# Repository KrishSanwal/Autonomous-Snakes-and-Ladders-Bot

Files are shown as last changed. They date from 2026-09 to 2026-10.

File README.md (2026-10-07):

# Automatic Snakes and Ladders Board





A Snakes and Ladders board that plays against a human. A CoreXY mechanism is used under the board and it moves a gondola connected to a magnet, which drags the machine's piece across the board. Features sensorless homing as seen in many FDM printers.

> **Status: work in progress.** Hardware is being sourced. Firmware is not written yet. Items marked `[TBC]` are not finalised. Do not order parts from this README until those are resolved.

---

## Table of contents

1. [Overview](#overview)
   - [Features](#features)
2. [How it works](#how-it-works)
   - [Electronics](#electronics)
3. [Bill of materials](#bill-of-materials)
   - [Motion parts](#motion-parts)
   - [Electronic parts](#electronic-parts)
   - [Fasteners](#fasteners)
   - [Tools](#tools)
4. [3D Files](#3d-files)
   - [Full System with Top](#full-system-with-top)
   - [Full System](#full-system)
   - [Outer Frame](#outer-frame)
   - [Gondola System](#gondola-system)
   - [Top Cover](#top-cover)
6. [Wiring Diagram](#wiring-diagram)
7. [Licence](#licence)
8. [Author](#author)

---

## Overview

I made this project as there is a lot of use of CoreXY Mechanisms in large industrial machines such as CNCs, 3D Printers, Mills etc. Showcasing this mechanism through a board game makes it easy to understand as you do not have any other pieces except the ones needed for 2D movement.

### Features

- Plays a game of Snakes and Ladders against a human.
- Moves its own piece from under the board with a magnet, no visible mechanism.
- Remembers the position of the human's piece and it's piece so it knows who won.
- Sensor-less homing and therefore no limit switches are needed.
- Dice is rolled on an OLED display using a button.
- Runs on an Arduino Uno with a CNC Shield unit on it therefore does not need a custom PCB.

---

## How it works

This board uses a CoreXY Mechanism that consists of two static motors (motors don't move) on the front end of the board that control the main magnetic piece using timing belts. The movement happens by spinning either one of the motors or both of them. The motors move the magnetic gondola to set positions that translate to movement on the top board surface where a magnetic piece moves with the gondola. The game is played turn based and the dice is on a OLED screen activated by a push button. An E-Dice will help the machine know how much to move and also helps to tell the machine if the player has reached the end without the use of any physical sensors.

### Electronics

- Arduino Uno R3 with CNC Shield V3
- 2x NEMA 17 Stepper Motors
- 2x TMC2209 stepper drivers
- 1.3 inch I2C OLED for dice and messages
- 16 mm illuminated push button (Lanboo LB16QC, 5-24 V, 1NO)
- 5 V active buzzer
- 12 V 5 A supply with a rocker switch on the 12 V positive line

---

## Bill of materials

### Motion parts

| Qty | Part | Price (USD) | Price (INR) | Link |
|---:|---|---:|---:|---|
| 2 | StepperOnline 17HE15-1504S NEMA17 (42 N·cm, 1.5 A, 1 m detachable cable) | $15.64 | ₹1,498.00 | [Robu](https://robu.in/product/stepperonline-nema-17-42ncm-bipolar-stepper-motor/) |
| 2 (1 pack) | Aluminium GT2 20-tooth pulley, 5 mm bore, for 6 mm belt | $1.37 | ₹131.00 | [Robu](https://robu.in/product/aluminum-gt2-timing-pulley-for-6mm-belt-20-tooth-5mm-bore-2pcs/) |
| 8 | Flyrobo GT2 idler pulley without teeth, 5 mm bore, for 6 mm belt | $23.64 | ₹2,264.00 | [Amazon](https://www.amazon.in/gp/product/B0H7K3W1P3) |
| 2 | Self Lub GT2 timing belt 2 m x 6 mm, open | $9.38 | ₹898.00 | [Amazon](https://www.amazon.in/gp/product/B0HCLLLB88) |
| 6 (3 packs of 2) | INVENTO EN31 steel smooth rod 10 mm x 300 mm | $11.56 | ₹1,107.00 | [Amazon](https://www.amazon.in/gp/product/B071W8FKQV) |
| 8 | Two Trees SK10 (SH10A) rod support | $5.85 | ₹560.00 | [Robu](https://robu.in/product/sk10-10mm-linear-bearing-rail-support-xyz-shaft-table-cnc-router-sh10a/) |
| 4 | SC10UU 10 mm linear bearing block | $6.39 | ₹612.00 | [Robu](https://robu.in/product/sc10uu-10-mm-linear-ball-bearing-slide-unit-cnc-3d-printer/) |
| 1 pack | SNOOGG 12 x 2 mm N35 neodymium disc magnets (pack of 20) | $3.96 | ₹379.00 | [Amazon](https://www.amazon.in/gp/product/B0DMVKSZ74) |

### Electronic parts

| Qty | Part | Price (USD) | Price (INR) | Link |
|---:|---|---:|---:|---|
| 1 | Arduino Uno R3 with USB cable | $4.17 | ₹398.97 | [Robu](https://robu.in/product/arduino-uno-r3/) |
| 1 | CNC Shield V3 | $1.03 | ₹99.00 | [Robu](https://robu.in/product/cnc-shield-v3-engraving-machine-3d-printer-a4988-drv8825-driver-expansion-board/) |
| 2 | TMC2209 stepper driver module with heatsink (must expose DIAG and UART pins) | $13.55 | ₹1,298.00 | [Robu](https://robu.in/product/tmc2209-stepper-motor-driver-module-with-heatsink/) |
| 1 | 12 V 5 A 60 W power supply, 5.5 mm DC plug | $4.44 | ₹425.00 | [Robu](https://robu.in/product/orange-ac-100-240v-to-dc-12v-5a-60w-power-adapter/) |
| 1 | DC jack socket (female) with moulded wire lead, 15 cm | $0.22 | ₹21.00 | [Robu](https://robu.in/product/5mm-dc-jack-socket-female-jack-socket-with-wire/) |
| 1 | Electronic Spices DC female to 2 male Y-splitter cable | $1.24 | ₹119.00 | [Amazon](https://www.amazon.in/gp/product/B08PRS2Q23) |
| 1 | 6A 250V AC SPST ON-OFF rocker switch | $0.17 | ₹16.00 | [Robu](https://robu.in/product/6a-250v-ac-spst-on-off-rocker-switch/) |
| 1 | 1.3 inch I2C OLED display, blue | $3.02 | ₹289.00 | [Robu](https://robu.in/product/1-3-inch-i2c-iic-4-pin-oled-display-module-with-vcc-gnd-blue/) |
| 1 | Lanboo LB16QC-P10F 16 mm push button switch, blue, DC 5-24V, 1NO | $4.62 | ₹442.00 | [Robu](https://robu.in/product/lb16qc-p10f-lanboo-16mm-tact-push-button-switch-bluedc-5-24v1no/) |
| 1 | 5 V active buzzer | $0.17 | ₹16.00 | [Robu](https://robu.in/product/5v-active-electromagnetic-buzzer-pack-of-5/) |
| 17 (1 needed) | 1 kΩ 0.25 W metal film resistor (UART TX to RX link) | $0.11 | ₹10.20 | [Robu](https://robu.in/product/1k-ohm-0-25w-metal-film-resistor-pack-of-100/) |
| 2 | 1000 µF 25 V electrolytic capacitor (12 V input) | $0.23 | ₹22.00 | [Robu](https://robu.in/product/1000uf-25v-electrolytic-capacitor-dip-pack-of-5/) |
| 4 (3 needed, 2 works) | Rubycon 35ZLH100M 100 µF 35 V electrolytic capacitor (driver VMOT) | $0.16 | ₹15.64 | [Robu](https://robu.in/product/35zlh100mefct16-3x11-rubycon-100uf-35v-%c2%b120-plugind6-3xl11mm-aluminum-electrolytic-capacitors-leaded-rohs/) |
| 1 set | Dupont jumper wires, female-female, 20 cm, 40 pcs | $0.43 | ₹41.00 | [Robu](https://robu.in/product/20cm-dupont-wire-color-jumper-cable-2-54mm-1p-1p-female-female-40pcs/) |
| 1 set | Dupont jumper wires, male-female, 20 cm, 10 pcs | $0.14 | ₹13.00 | [Robu](https://robu.in/product/10-wire-male-to-female-jumper-wires-20cm/) |
| 4 | 3 mm black heat shrink sleeve | $0.25 | ₹24.00 | [Robu](https://robu.in/product/heat-shrink-sleeve-3mm-black-industrial-grade-woer-hst/) |

### Fasteners

| Qty | Part | Price (USD) | Price (INR) | Link |
|---:|---|---:|---:|---|
| 10 | M5 x 35mm Phillips pan head screw | $0.29 | ₹28.00 | [OnlyScrews](https://onlyscrews.in/products/m5-x-35mm-phillips-pan-head-mild-steel-with-zinc-blue-plating-screw-dia-5mm-length-35mm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) |
| 20 | M5 x 15mm Phillips pan head screw | $0.33 | ₹32.00 | [OnlyScrews](https://onlyscrews.in/products/m5-x-15mm-phillips-pan-head-mild-steel-with-zinc-blue-plating-screw-dia-5mm-length-15mm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) |
| 25 | M5 x 10mm Phillips pan head screw | $0.37 | ₹35.00 | [OnlyScrews](https://onlyscrews.in/products/m5-x-10mm-phillips-pan-head-mild-steel-with-zinc-blue-plating-screw-dia-5mm-length-10mm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) |
| 67 | M5 x 5mm brass threaded inserts | $1.54 | ₹147.40 | [OnlyScrews](https://onlyscrews.in/products/m5-x-5mm-brass-threaded-inserts-dia-5mm-length-5mm?variant=51217096835385) |
| 30 | M3 x 3mm brass threaded inserts | $0.75 | ₹72.00 | [OnlyScrews](https://onlyscrews.in/products/m3-x-3mm-brass-threaded-inserts?variant=49729062273337) |
| 25 | M5 plain washer SS304 (ID 5.4mm, OD 9.8mm, T 1mm) | $0.31 | ₹30.00 | [OnlyScrews](https://onlyscrews.in/products/m5-washer-ss304?variant=48883899105593) |
| 9 | M3 x 6mm Phillips pan head screw SS304 | $0.15 | ₹14.40 | [OnlyScrews](https://onlyscrews.in/products/phillips-pan-head-m3-x-6mm-pack-of-20?variant=48468588757305) |
| 15 | M3 x 10mm Phillips pan head screw SS304 | $0.28 | ₹27.00 | [OnlyScrews](https://onlyscrews.in/products/phillips-pan-head-m3-x-10mm-pack-of-20?variant=48468583874873) |
| 5 | M3 x 16mm Phillips pan head screw SS304 | $0.11 | ₹11.00 | [OnlyScrews](https://onlyscrews.in/products/phillips-pan-head-m3-x-16mm-pack-of-20?variant=48468578959673) |
| 4 | M5 hex nut SS304 | $0.058 | ₹5.60 | [OnlyScrews](https://onlyscrews.in/a/search?q=m5+nut&options%5Bprefix%5D=last) |

### Tools

| Qty | Part | Price (USD) | Price (INR) | Link |
|---:|---|---:|---:|---|
| 1 | UNI-T UT890D+ digital multimeter, True RMS 6000 count | $19.83 | ₹1,899.00 | [Robu](https://robu.in/product/uni-t-ut890d-digital-multimeter/) |
| 1 | Serplex 12-in-1 soldering iron tool kit 80W | $16.70 | ₹1,599.00 | [Amazon](https://www.amazon.in/gp/product/B0G2H4J193) |

3D printer: parts here are made on a Bambu Lab P2S.

### Total

**~$154 (₹14,599.21)**

---

## 3D Files

### Full System With Top



### Full System



### Outer Frame



### Gondola System



## Top Cover



---

## Wiring Diagram
This project does not use a custom PCB rather relies on an Arduino Board with a CNC Shield Attachment.



---

## Licence

Licensed under CC BY-NC-SA 4.0. See [LICENSE](LICENSE).

Personal, educational and classroom use is welcome. You may build it, modify it and share your changes under the same licence, with credit.

Selling is not permitted: no assembled units, kits, printed parts, files or firmware, original or modified. For commercial licensing, contact me.

This project is source-available, not open source as defined by OSI or OSHWA.

Third-party libraries remain under their own licences.

---

## Author

Krish Sanwal
https://github.com/KrishSanwal

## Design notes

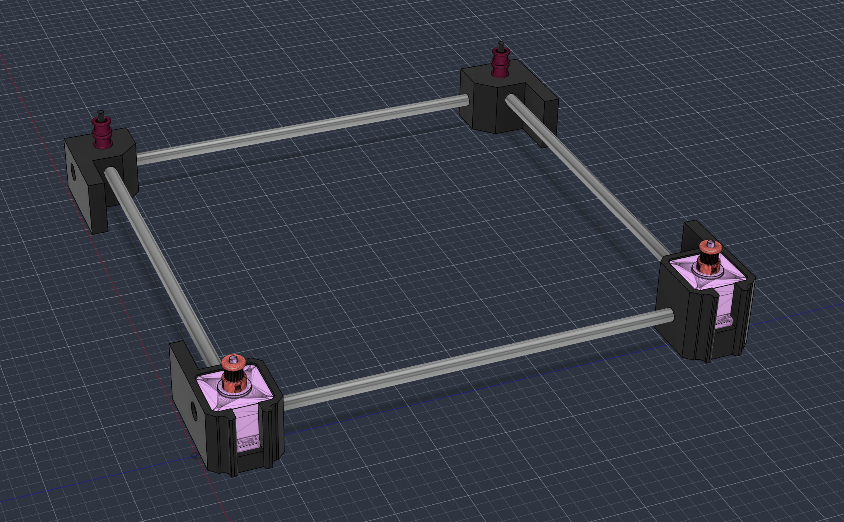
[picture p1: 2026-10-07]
3D Files/Outer Frame.png

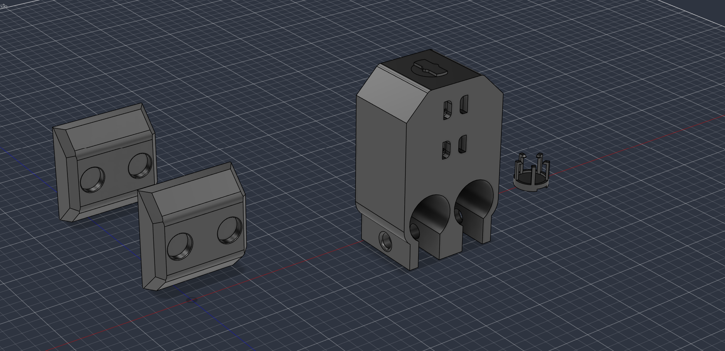
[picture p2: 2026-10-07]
3D Files/Gondola Sliding System.png

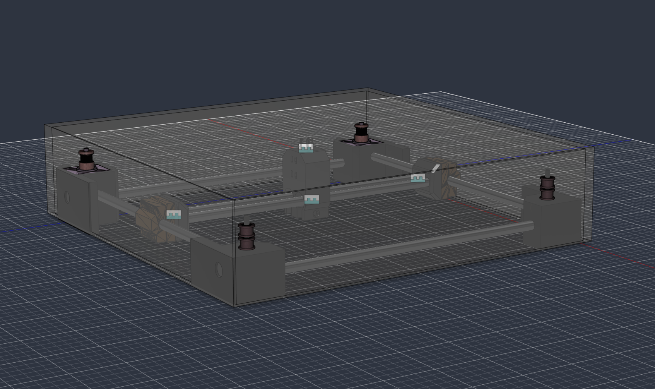
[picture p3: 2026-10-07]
3D Files/Complete Board Asembly.png

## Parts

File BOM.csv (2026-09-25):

Item Name | Qty | Price (total) (USD) | Item link | Notes
Two Trees SH10A SK10 10mm linear bearing rail support | 8 | $5.85 (INR 560.00) | https://robu.in/product/sk10-10mm-linear-bearing-rail-support-xyz-shaft-table-cnc-router-sh10a/
SC10UU 10 mm linear ball bearing slide unit | 4 | $6.39 (INR 612.00) | https://robu.in/product/sc10uu-10-mm-linear-ball-bearing-slide-unit-cnc-3d-printer/
Aluminum GT2 timing pulley 20 tooth 5mm bore for 6mm belt (2 pcs) | 1 | $1.37 (INR 131.00) | https://robu.in/product/aluminum-gt2-timing-pulley-for-6mm-belt-20-tooth-5mm-bore-2pcs/
Arduino Uno R3 with cable | 1 | $4.17 (INR 398.97) | https://robu.in/product/arduino-uno-r3/
CNC Shield V3 | 1 | $1.03 (INR 99.00) | https://robu.in/product/cnc-shield-v3-engraving-machine-3d-printer-a4988-drv8825-driver-expansion-board/
TMC2209 stepper motor driver module with heatsink | 2 | $13.55 (INR 1298.00) | https://robu.in/product/tmc2209-stepper-motor-driver-module-with-heatsink/
Standard 12V 5A 60W power supply with 5.5mm DC plug | 1 | $4.44 (INR 425.00) | https://robu.in/product/orange-ac-100-240v-to-dc-12v-5a-60w-power-adapter/
20cm Dupont jumper cable female to female, 40 pcs | 1 | $0.43 (INR 41.00) | https://robu.in/product/20cm-dupont-wire-color-jumper-cable-2-54mm-1p-1p-female-female-40pcs/
10 wire male to female jumper wires, 20cm | 1 | $0.14 (INR 13.00) | https://robu.in/product/10-wire-male-to-female-jumper-wires-20cm/
1k ohm 0.25W metal film resistor | 17 | $0.11 (INR 10.20) | https://robu.in/product/1k-ohm-0-25w-metal-film-resistor-pack-of-100/ | 1 needed, 16 extra as the site im ordering from (robu.in) does not allow ordering components below 10 rupees
1000uF 25V electrolytic capacitor | 2 | $0.23 (INR 22.00) | https://robu.in/product/1000uf-25v-electrolytic-capacitor-dip-pack-of-5/ | 1 needed, 1 extra
Rubycon 35ZLH100M 100uF 35V electrolytic capacitor | 4 | $0.16 (INR 15.64) | https://robu.in/product/35zlh100mefct16-3x11-rubycon-100uf-35v-%c2%b120-plugind6-3xl11mm-aluminum-electrolytic-capacitors-leaded-rohs/ | 3 needed, 1 extra
Heat shrink sleeve 3mm black (WOER) | 4 | $0.25 (INR 24.00) | https://robu.in/product/heat-shrink-sleeve-3mm-black-industrial-grade-woer-hst/
StepperOnline 17HE15-1504S NEMA17 stepper motor 42Ncm 1.5A with 1m cable | 2 | $15.64 (INR 1498.00) | https://robu.in/product/stepperonline-nema-17-42ncm-bipolar-stepper-motor/
5mm DC jack socket female connector with moulded wire, 15cm | 1 | $0.22 (INR 21.00) | https://robu.in/product/5mm-dc-jack-socket-female-jack-socket-with-wire/
1.3 inch I2C 4 pin OLED display module, blue | 1 | $3.02 (INR 289.00) | https://robu.in/product/1-3-inch-i2c-iic-4-pin-oled-display-module-with-vcc-gnd-blue/
5V active electromagnetic buzzer | 1 | $0.17 (INR 16.00) | https://robu.in/product/5v-active-electromagnetic-buzzer-pack-of-5/
Lanboo LB16QC-P10F 16mm push button switch, blue, DC 5-24V, 1NO | 1 | $4.62 (INR 442.00) | https://robu.in/product/lb16qc-p10f-lanboo-16mm-tact-push-button-switch-bluedc-5-24v1no/
6A 250V AC SPST ON-OFF rocker switch | 1 | $0.17 (INR 16.00) | https://robu.in/product/6a-250v-ac-spst-on-off-rocker-switch/
UNI-T UT890D+ digital multimeter, True RMS 6000 count | 1 | $19.83 (INR 1899.00) | https://robu.in/product/uni-t-ut890d-digital-multimeter/
Serplex 12-in-1 soldering iron tool kit 80W | 1 | $16.70 (INR 1599.00) | https://www.amazon.in/gp/product/B0G2H4J193
Electronic Spices DC female to 2 male Y-splitter cable | 1 | $1.24 (INR 119.00) | https://www.amazon.in/gp/product/B08PRS2Q23
INVENTO EN31 steel smooth rod 10mm x 300mm (2 pcs) | 3 | $11.56 (INR 1107.00) | https://www.amazon.in/gp/product/B071W8FKQV
SNOOGG 12 x 2 mm N35 neodymium disc magnets, pack of 20 | 1 | $3.96 (INR 379.00) | https://www.amazon.in/gp/product/B0DMVKSZ74
Flyrobo GT2 idler pulley without teeth, 5mm bore, for 6mm belt | 8 | $23.64 (INR 2264.00) | https://www.amazon.in/gp/product/B0H7K3W1P3
Self Lub GT2 timing belt 2 m x 6mm, open | 2 | $9.38 (INR 898.00) | https://www.amazon.in/gp/product/B0HCLLLB88
M5 x 35mm Phillips pan head screw | 10 | $0.29 (INR 28.00) | https://onlyscrews.in/products/m5-x-35mm-phillips-pan-head-mild-steel-with-zinc-blue-plating-screw-dia-5mm-length-35mm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
M5 x 15mm Phillips pan head screw | 20 | $0.33 (INR 32.00) | https://onlyscrews.in/products/m5-x-15mm-phillips-pan-head-mild-steel-with-zinc-blue-plating-screw-dia-5mm-length-15mm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
M5 x 10mm Phillips pan head screw | 25 | $0.37 (INR 35.00) | https://onlyscrews.in/products/m5-x-10mm-phillips-pan-head-mild-steel-with-zinc-blue-plating-screw-dia-5mm-length-10mm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
M5 x 5mm brass threaded inserts | 67 | $1.54 (INR 147.40) | https://onlyscrews.in/products/m5-x-5mm-brass-threaded-inserts-dia-5mm-length-5mm?variant=51217096835385
M3 x 3mm Brass Threaded Inserts | 30 | $0.75 (INR 72.00) | https://onlyscrews.in/products/m3-x-3mm-brass-threaded-inserts?variant=49729062273337
M5 plain washer SS304 (ID 5.4mm, OD 9.8mm, T 1mm) | 25 | $0.31 (INR 30.00) | https://onlyscrews.in/products/m5-washer-ss304?variant=48883899105593
M3 x 6mm Phillips pan head screw SS304 | 9 | $0.15 (INR 14.40) | https://onlyscrews.in/products/phillips-pan-head-m3-x-6mm-pack-of-20?variant=48468588757305
M3 x 10mm Phillips pan head screw SS304 | 15 | $0.28 (INR 27.00) | https://onlyscrews.in/products/phillips-pan-head-m3-x-10mm-pack-of-20?variant=48468583874873
M3 x 16mm Phillips pan head screw SS304 | 5 | $0.11 (INR 11.00) | https://onlyscrews.in/products/phillips-pan-head-m3-x-16mm-pack-of-20?variant=48468578959673
M5 Hex Nut SS304 | 4 | $0.058 (INR 5.60) | https://onlyscrews.in/a/search?q=m5+nut&options%5Bprefix%5D=last
Total Price (USD): | ~$154 (INR 14,599.21) |  |  | 1 USD = 95.77 INR

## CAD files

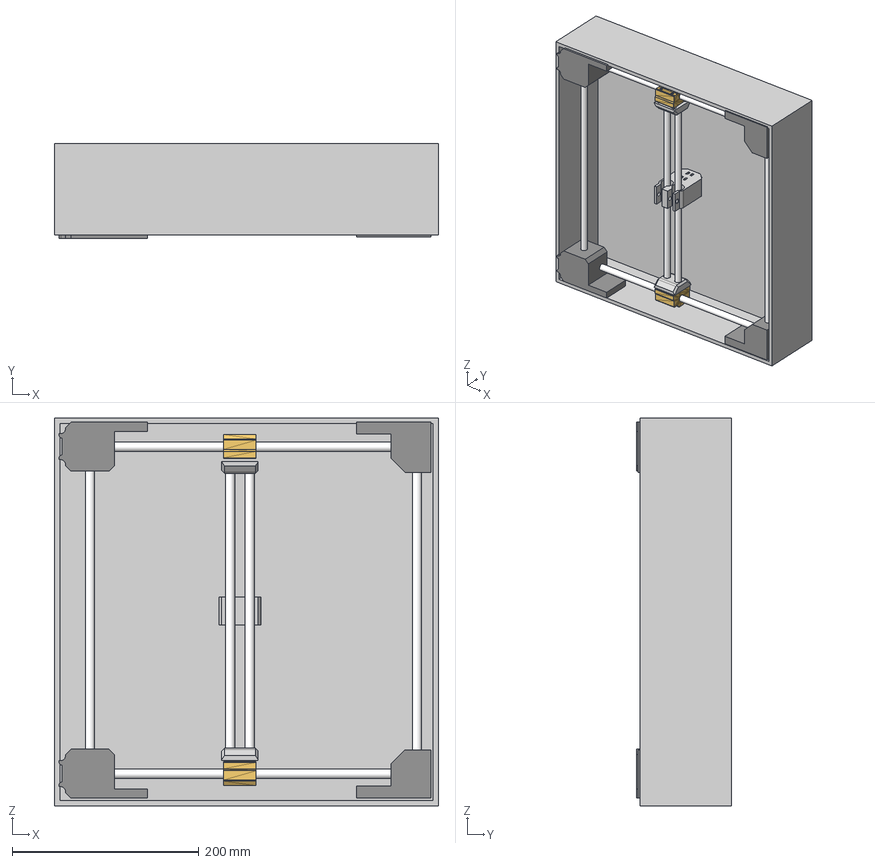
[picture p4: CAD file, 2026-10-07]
3D Files/CoreXY Snakes And Ladders Board Assembly.step
411.0 x 101.3 x 415.0 mm

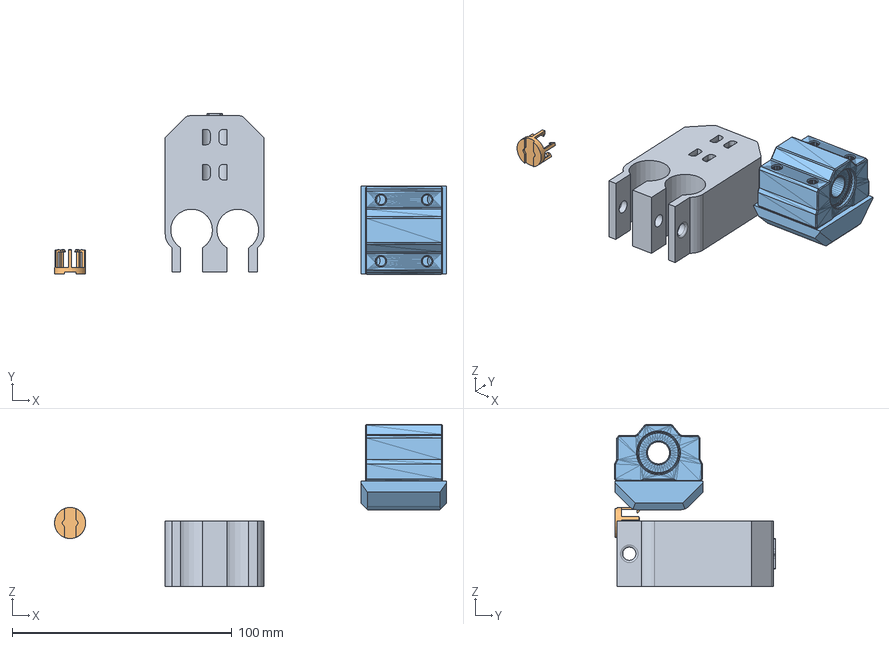
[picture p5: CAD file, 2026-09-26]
3D Files/Gondola Sliding system.step
178.4 x 73.2 x 73.9 mm

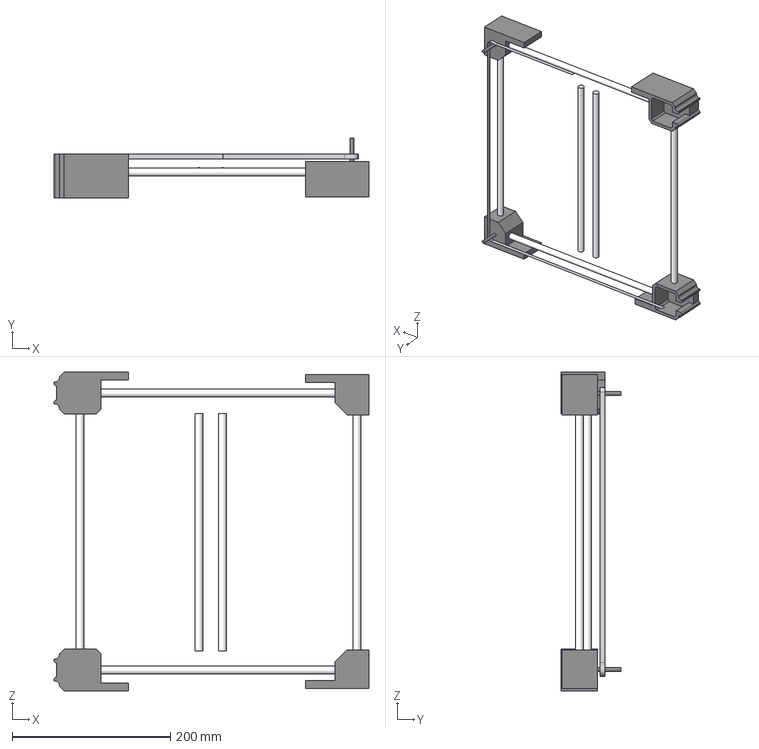
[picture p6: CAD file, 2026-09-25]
3D Files/Outer Frame.step
398.0 x 76.0 x 402.6 mm

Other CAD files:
3D Files/CoreXY Assembly.f3z
3D Files/Gondola Sliding system.f3d
3D Files/Outer Frame.f3d

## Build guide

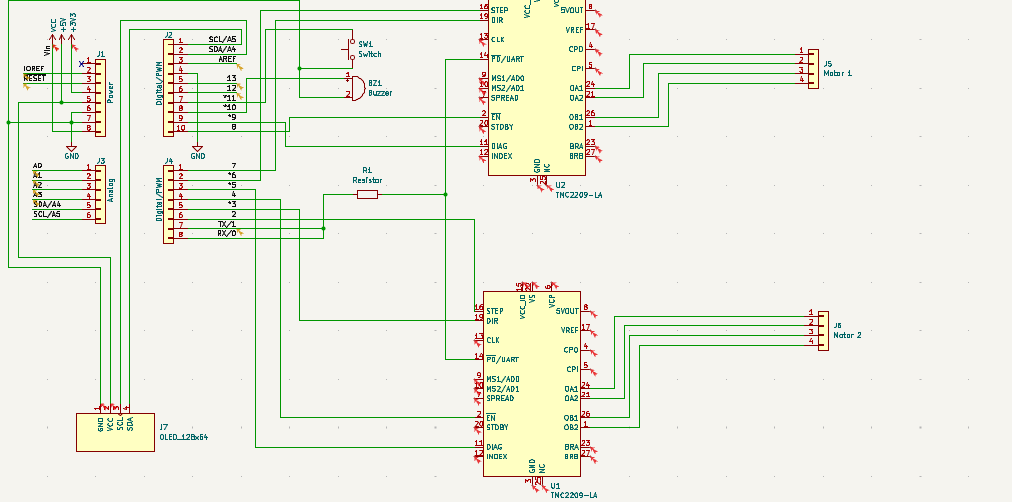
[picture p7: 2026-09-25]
Wiring/Wiring Schematic.png

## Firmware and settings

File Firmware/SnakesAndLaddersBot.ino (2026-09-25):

// Autonomous Snakes & Ladders Bot
// CoreXY gondola under the board drags a magnetic piece to each square.
// TMC2209 sensorless homing, shared single-wire UART, OLED status display.
//
// Libraries required (Library Manager):
//   TMCStepper      by teemuatlut
//   AccelStepper    by Mike McCauley
//   Adafruit GFX Library
//   Adafruit SSD1306

#include <TMCStepper.h>
#include <AccelStepper.h>
#include <Wire.h>
#include <Adafruit_GFX.h>
#include <Adafruit_SSD1306.h>
#include <EEPROM.h>
#include "config.h"

// ---- drivers (share one Serial/UART bus, told apart by address) ----
TMC2209Stepper driverA(&Serial, R_SENSE, DRIVER_ADDR_A);
TMC2209Stepper driverB(&Serial, R_SENSE, DRIVER_ADDR_B);

// ---- steppers ----
AccelStepper stepperA(AccelStepper::DRIVER, STEP_A_PIN, DIR_A_PIN);
AccelStepper stepperB(AccelStepper::DRIVER, STEP_B_PIN, DIR_B_PIN);

// ---- OLED ----
#define SCREEN_WIDTH 128
#define SCREEN_HEIGHT 64
Adafruit_SSD1306 display(SCREEN_WIDTH, SCREEN_HEIGHT, &Wire, -1);

// The bot only has a magnet for its OWN piece, but the roll (dice) is
// onboard and used for BOTH turns, so software has to track both
// players' squares to know who's ahead and who's won.
int humanSquare = 1;
int botSquare = 1;

// EEPROM layout: [0]=magic byte, [1]=humanSquare, [2]=botSquare
#define EEPROM_MAGIC_ADDR    0
#define EEPROM_HUMAN_ADDR    1
#define EEPROM_BOT_ADDR      2
#define EEPROM_MAGIC_VALUE   0x5A   // marks "state has been saved at least once"

void saveState() {
  EEPROM.update(EEPROM_MAGIC_ADDR, EEPROM_MAGIC_VALUE);
  EEPROM.update(EEPROM_HUMAN_ADDR, (uint8_t)humanSquare);
  EEPROM.update(EEPROM_BOT_ADDR, (uint8_t)botSquare);
}

bool loadState() {
  if (EEPROM.read(EEPROM_MAGIC_ADDR) != EEPROM_MAGIC_VALUE) return false; // nothing saved yet
  humanSquare = EEPROM.read(EEPROM_HUMAN_ADDR);
  botSquare = EEPROM.read(EEPROM_BOT_ADDR);
  if (humanSquare < 1 || humanSquare > 100) humanSquare = 1; // sanity check
  if (botSquare < 1 || botSquare > 100) botSquare = 1;
  return true;
}

// ============================================================
// SETUP
// ============================================================
void setup() {
  pinMode(EN_A_PIN, OUTPUT);
  pinMode(EN_B_PIN, OUTPUT);
  pinMode(DIAG_A_PIN, INPUT);
  pinMode(DIAG_B_PIN, INPUT);
  pinMode(BUTTON_PIN, INPUT_PULLUP);
  pinMode(BUZZER_PIN, OUTPUT);

  digitalWrite(EN_A_PIN, LOW);   // active LOW = enabled
  digitalWrite(EN_B_PIN, LOW);

  Serial.begin(115200);          // this is the shared TMC2209 UART bus, not a USB debug console
  driverA.begin();
  driverB.begin();
  setupDriver(driverA);
  setupDriver(driverB);

  stepperA.setMaxSpeed(RUN_SPEED_SPS);
  stepperA.setAcceleration(RUN_ACCEL_SPS2);
  stepperB.setMaxSpeed(RUN_SPEED_SPS);
  stepperB.setAcceleration(RUN_ACCEL_SPS2);

  Wire.begin();
  display.begin(SSD1306_SWITCHCAPVCC, 0x3C);
  showMessage("Booting...");

  randomSeed(analogRead(A0));   // leave A0 floating/unconnected — needed for real randomness

  bool resumed = loadState();   // false on very first boot ever, or if EEPROM was blank

  homeAxes();                    // motors always need a fresh physical reference after power-up

  if (!resumed) {
    humanSquare = 1;
    botSquare = 1;
    saveState();
  }
  moveToSquare(botSquare);       // put the gondola back where the bot's piece actually was
  showStatus();
}

// Common per-driver config. TMC2209 loses this on every power cycle,
// which is why it lives in setup() rather than being a one-time flash.
void setupDriver(TMC2209Stepper &drv) {
  drv.toff(5);
  drv.rms_current(MOTOR_RMS_CURRENT_MA);
  drv.microsteps(MICROSTEPS);
  drv.en_spreadCycle(false);      // stealthChop for quiet running
  drv.pwm_autoscale(true);
  drv.TCOOLTHRS(0xFFFFF);         // enable StallGuard across full speed range for homing
  drv.SGTHRS(STALLGUARD_THRESHOLD);
}

// ============================================================
// MAIN LOOP
// ============================================================
bool gameOver = false;

void loop() {
  if (!gameOver && digitalRead(BUTTON_PIN) == LOW) {
    delay(30);                    // debounce
    if (digitalRead(BUTTON_PIN) == LOW) {
      playRound();
      while (digitalRead(BUTTON_PIN) == LOW) { /* wait for release */ }
    }
  }
}

// ============================================================
// GAME LOGIC
// One button press = one full round: human rolls (onboard dice,
// software-only move — human slides their own piece by hand to
// match the displayed number), then the bot auto-rolls and the
// gondola physically drives its piece there.
// ============================================================
void playRound() {
  // ---- human's roll ----
  int humanRoll = random(1, 7);
  showMessage(("Your roll: " + String(humanRoll)).c_str());
  beep(1);
  delay(1200);   // give them time to read it and move their piece by hand

  int humanTarget = humanSquare + humanRoll;
  if (humanTarget > 100) humanTarget = humanSquare; // must land exactly on 100
  humanSquare = applyJump(humanTarget, false);
  saveState();   // saved here, after humanSquare holds the final post-jump value

  if (humanSquare == 100) {
    endGame("You win!");
    return;
  }

  // ---- bot's roll, automatic, no second button press ----
  delay(600);
  int botRoll = random(1, 7);
  showMessage(("Bot roll: " + String(botRoll)).c_str());
  delay(500);

  int botTarget = botSquare + botRoll;
  if (botTarget > 100) botTarget = botSquare;

  moveToSquare(botTarget);
  botSquare = botTarget;
  saveState();   // save right after the physical move so gondola position always matches saved square

  botSquare = applyJump(botSquare, true);
  saveState();   // saved here, after botSquare holds the final post-jump value

  if (botSquare == 100) {
    endGame("Bot wins!");
    return;
  }

  showStatus();
}

// Checks a square for a snake/ladder, beeps, and — for the bot only —
// physically drives the gondola to the destination. Returns the
// final resting square after any jump.
int applyJump(int square, bool isBot) {
  int jumped = checkSnakeOrLadder(square);
  if (jumped == square) {
    beep(1);
    return square;
  }
  delay(400);
  bool isLadder = jumped > square;
  beep(isLadder ? 2 : 1);         // 2 short beeps = ladder, 1 long = snake
  if (isBot) {
    moveToSquare(jumped);
  }
  return jumped;
}

void endGame(const char *msg) {
  gameOver = true;
  saveState();
  showMessage(msg);
}

int checkSnakeOrLadder(int square) {
  for (int i = 0; i < NUM_JUMPS; i++) {
    if (SNAKES_AND_LADDERS[i].from == square) {
      return SNAKES_AND_LADDERS[i].to;
    }
  }
  return square;
}

// ============================================================
// SQUARE -> BOARD COORDINATE (boustrophedon numbering)
// Square 1 = bottom-left, row 0 goes left->right,
// row 1 goes right->left, and so on.
// ============================================================
void squareToXY(int square, float &xmm, float &ymm) {
  int idx = square - 1;
  int row = idx / BOARD_SIZE;
  int col = idx % BOARD_SIZE;
  if (row % 2 == 1) col = (BOARD_SIZE - 1) - col;

  xmm = col * SQUARE_SIZE_MM + SQUARE_SIZE_MM / 2.0f;
  ymm = row * SQUARE_SIZE_MM + SQUARE_SIZE_MM / 2.0f;
}

void moveToSquare(int square) {
  float x, y;
  squareToXY(square, x, y);
  moveToXY(x, y);
}

// ============================================================
// CoreXY MOTION
// stepsA = x + y, stepsB = x - y  (relative to the homed corner)
// ============================================================
void moveToXY(float xmm, float ymm) {
  long xSteps = lround(xmm * STEPS_PER_MM);
  long ySteps = lround(ymm * STEPS_PER_MM);

  long targetA = xSteps + ySteps;
  long targetB = xSteps - ySteps;

  stepperA.moveTo(targetA);
  stepperB.moveTo(targetB);

  while (stepperA.distanceToGo() != 0 || stepperB.distanceToGo() != 0) {
    stepperA.run();
    stepperB.run();
  }
}

// ============================================================
// SENSORLESS HOMING
// Moves both motors together (equal sign = pure X, opposite
// sign = pure Y) until either DIAG pin flags a stall.
// ============================================================
void homeAxes() {
  showMessage("Homing X...");
  homeOneAxis(true);   // pure X
  showMessage("Homing Y...");
  homeOneAxis(false);  // pure Y

  stepperA.setCurrentPosition(0);
  stepperB.setCurrentPosition(0);
}

void homeOneAxis(bool isX) {
  long maxSteps = lround(HOMING_MAX_TRAVEL_MM * STEPS_PER_MM);
  long backoffSteps = lround(HOMING_BACKOFF_MM * STEPS_PER_MM);

  stepperA.setMaxSpeed(HOMING_SPEED_SPS);
  stepperA.setAcceleration(HOMING_ACCEL_SPS2);
  stepperB.setMaxSpeed(HOMING_SPEED_SPS);
  stepperB.setAcceleration(HOMING_ACCEL_SPS2);

  // isX: both motors move the same direction -> pure X travel
  // !isX: motors move opposite directions -> pure Y travel
  stepperA.move(-maxSteps);
  stepperB.move(isX ? -maxSteps : maxSteps);

  bool stalled = false;
  while (!stalled && (stepperA.distanceToGo() != 0 || stepperB.distanceToGo() != 0)) {
    if (digitalRead(DIAG_A_PIN) == HIGH || digitalRead(DIAG_B_PIN) == HIGH) {
      stalled = true;
      break;
    }
    stepperA.run();
    stepperB.run();
  }

  stepperA.stop();
  stepperB.stop();
  stepperA.setCurrentPosition(stepperA.currentPosition());
  stepperB.setCurrentPosition(stepperB.currentPosition());

  // back off the corner
  stepperA.move(isX ? backoffSteps : backoffSteps);
  stepperB.move(isX ? backoffSteps : -backoffSteps);
  while (stepperA.distanceToGo() != 0 || stepperB.distanceToGo() != 0) {
    stepperA.run();
    stepperB.run();
  }

  stepperA.setMaxSpeed(RUN_SPEED_SPS);
  stepperA.setAcceleration(RUN_ACCEL_SPS2);
  stepperB.setMaxSpeed(RUN_SPEED_SPS);
  stepperB.setAcceleration(RUN_ACCEL_SPS2);
}

// ============================================================
// OLED + BUZZER HELPERS
// ============================================================
void showMessage(const char *msg) {
  display.clearDisplay();
  display.setTextSize(1);
  display.setTextColor(SSD1306_WHITE);
  display.setCursor(0, 0);
  display.println(msg);
  display.display();
}

void showStatus() {
  display.clearDisplay();
  display.setTextSize(1);
  display.setTextColor(SSD1306_WHITE);
  display.setCursor(0, 0);
  display.println("Snakes & Ladders");
  display.setCursor(0, 16);
  display.print("You: ");
  display.println(humanSquare);
  display.setCursor(0, 28);
  display.print("Bot: ");
  display.println(botSquare);
  display.setCursor(0, 50);
  display.println("Press button to roll");
  display.display();
}

void beep(int times) {
  for (int i = 0; i < times; i++) {
    tone(BUZZER_PIN, 2000, 150);
    delay(200);
  }
}

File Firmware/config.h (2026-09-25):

#pragma once

// ============================================================
// PIN MAP — matches the KiCad schematic wiring table
// ============================================================
// Driver A = U1, UART address 0 (MS1/AD0 tied to GND)
//   -> physically wired to motor connector J6 ("Motor 2" on schematic)
// Driver B = U2, UART address 1 (MS1/AD0 tied to VCC_IO)
//   -> physically wired to motor connector J5 ("Motor 1" on schematic)
// If you want the silkscreen labels to match, swap the two
// TMC2209Stepper objects in the .ino instead of rewiring.

#define STEP_A_PIN   2
#define DIR_A_PIN    3
#define EN_A_PIN     4
#define DIAG_A_PIN   5

#define STEP_B_PIN   6
#define DIR_B_PIN    7
#define EN_B_PIN     8
#define DIAG_B_PIN   9

#define BUZZER_PIN   10
#define BUTTON_PIN   11

// UART bus: shared PD/UART line on both drivers, joined to
// Arduino D0 (RX) / D1 (TX) through the 1k resistor (R1).
// This means the USB serial monitor is NOT available for debug
// prints while the drivers are active — use the OLED for status.
#define DRIVER_ADDR_A   0b00
#define DRIVER_ADDR_B   0b01
#define R_SENSE         0.11f   // check your TMC2209 module's sense resistor silkscreen — common value, not guaranteed

// ============================================================
// MOTION / CoreXY CONSTANTS — tune these to your actual build
// ============================================================
#define STEPS_PER_REV     200     // 1.8° NEMA17
#define MICROSTEPS        16      // set to match driver config below
#define PULLEY_TEETH      20      // GT2 20T pulley
#define BELT_PITCH_MM     2.0f    // GT2 = 2mm pitch
#define MM_PER_REV        (PULLEY_TEETH * BELT_PITCH_MM)                // 40mm
#define STEPS_PER_MM      ((STEPS_PER_REV * MICROSTEPS) / MM_PER_REV)   // 80 steps/mm at 16x

#define HOMING_SPEED_SPS      400   // steps/sec while seeking the stall
#define HOMING_ACCEL_SPS2     200
#define HOMING_BACKOFF_MM     5.0f
#define HOMING_MAX_TRAVEL_MM  350.0f  // generous over-travel bound, stall should trigger well before this

#define RUN_SPEED_SPS     2000
#define RUN_ACCEL_SPS2    1500

#define STALLGUARD_THRESHOLD  70   // 0-255, LOWER = more sensitive. Start high, lower until it triggers reliably without false-triggering mid-move
#define MOTOR_RMS_CURRENT_MA  1200 // set below your motor's rated current, raise only if it's losing steps

// ============================================================
// BOARD GEOMETRY
// ============================================================
#define BOARD_SIZE       10        // 10x10 squares = 100 squares
#define SQUARE_SIZE_MM    30.0f    // 300mm board / 10

// ============================================================
// SNAKES & LADDERS MAP — edit to match your printed board
// Format: {from, to}. from > to = snake, from < to = ladder.
// ============================================================
struct JumpPair { int from; int to; };

const JumpPair SNAKES_AND_LADDERS[] = {
  {4, 25},   // ladder
  {13, 46},  // ladder
  {33, 49},  // ladder
  {42, 63},  // ladder
  {50, 69},  // ladder
  {62, 81},  // ladder
  {74, 92},  // ladder
  {27, 5},   // snake
  {40, 3},   // snake
  {43, 18},  // snake
  {54, 31},  // snake
  {66, 45},  // snake
  {76, 58},  // snake
  {89, 53},  // snake
  {99, 41},  // snake
};
const int NUM_JUMPS = sizeof(SNAKES_AND_LADDERS) / sizeof(JumpPair);

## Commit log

2026-09-21 Renaming BOM (1).csv to BOM.csv
    [BOM.csv]
2026-09-21 Rename BOM (1).csv to BOM.csv
    [BOM.csv]
2026-09-21 Update BOM.csv with new item entries
    [BOM.csv]
2026-09-21 updated the final price after removal of the brackets as they can be 3d printed for my need
    Updated BOM with new item prices and links.
    [BOM.csv]
2026-09-25 Rename Screenshot 2026-09-25 025327.png to Main Gantry (NOT FINAL)
2026-09-25 Rename Screenshot 2026-09-26 033833.png to Wiring Schematic
2026-09-26 Rename Wiring Schematic to Wiring Schematic.png
2026-09-26 Rename Main Gantry (NOT FINAL) to Main Gantry (NOT FINAL).png
2026-09-28 Insert BOM section in README
    Added BOM section with an image to the README.
2026-09-28 Fix BOM header and add image
    Updated BOM section header and added an additional image.
2026-09-28 Add Bill of Materials section to README
    Added a Bill of Materials section with component details, quantities, prices, and links.
2026-09-28 Revise BOM section with updated parts and pricing
    Updated the Bill of Materials (BOM) section in README.md to include pricing and links for various components. Removed outdated entries and added new parts with their respective costs.
2026-10-07 Add wiring diagram to README
    Added a wiring diagram section with an image.
2026-10-07 Rename Screenshot 2026-10-08 000244.png to Complete Board Asembly.png
2026-10-07 Rename Snakes And Ladders Player Final.step to Outer Frame.step
    [Outer Frame.step]
2026-10-07 Rename Snakes And Ladders Board.f3d to Outer Frame.f3d
    [Outer Frame.f3d]
2026-10-07 Rename Screenshot 2026-10-07 235632.png to Outer Frame.png
2026-10-07 Update README to specify CNC Shield functionality
    Clarified that the CNC Shield allows operation without a custom PCB.
2026-10-16 Modify BOM.csv with new items and pricing
    Updated BOM.csv with new item entries and adjusted total price.
2026-10-16 Rename Screenshot 2026-10-16 111323.png to CoreXY Assembly.png

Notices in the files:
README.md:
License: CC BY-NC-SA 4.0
